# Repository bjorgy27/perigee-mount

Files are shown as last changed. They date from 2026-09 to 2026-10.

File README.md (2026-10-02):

# PERIGEE gimbal

Fully 3D-printed azimuth/elevation pedestal for a dish up to 1 m (mesh), 15-20 lb payload, driven directly by two
goBILDA Stingray servo gearboxes (Stingray-4 on azimuth, 450 deg of travel; Stingray-9 on elevation, 200 deg), both
run open loop: they are positional servos, the pulse width is the position, and there is no encoder or feedback wire.
Controlled by an ST Nucleo-F401RE on the rotating head (USB serial to the PC running Perigee). Azimuth needs no slip ring: 1.25 turns
of travel run on a cable service loop. The azimuth axis runs on a greased printed plain bearing; elevation runs on the
Stingray-9's own ball-bearing hub-shaft on the right and a printed split bushing on the left. The only non-printed parts
are metric screws and nuts, the two gearboxes and the electronics.

Everything here is generated from `params.json` by `build.py` running inside FreeCAD 1.1 (headless).

```
./build.sh                              # regenerate everything (about 30 s): parts, assembly, exploded view, audit, exports, viewer bundle
.venv/bin/python tools_render.py        # OpenGL inspection renders into out/renders (moderngl on headless EGL, ~1 s)
.venv/bin/python tools_render.py --anim # cinematic assembly film -> out/renders/assembly.mp4 (30 fps, ~2 min)
.venv/bin/python tools_render.py --spot 1.5,9.5,36   # contact sheet of film frames at those seconds
python3 -m venv .venv && .venv/bin/pip install moderngl numpy pillow   # one-time renderer setup
```

The build also runs a **geometry audit** (every part one valid closed solid, BOP-checked, watertight mesh:
`out/geometry_audit.txt`) and an **overlap audit** over every pair of parts and every fastener against every part
(`out/overlap_audit.txt`); both must say `clean`. Export folders are wiped and regenerated on every build, so no
stale parts from older revisions linger. It also creates an **Exploded_Assembly** view (Assembly workbench > Exploded Views) with one move per part in assembly order,
so FreeCAD itself can animate the explosion with its slider.

## Hardware is real, and nothing threads into plastic
Every screw and nut is modelled (about 170 pieces) as App::Link instances of master parts in
`Hardware_Library`, placed with the same coordinates that cut their counterbores, nut pockets and nut traps.
All fasteners are ISO 4762 socket head cap screws in M3 / M4 / M5 with ISO 4032 hex nuts. No heat-set inserts and
no self-tapping: each bolt ends in a nut, or in one of the gearboxes' own M4 threads, that sits either in a blind hex pocket on the far face (where that face is
reachable at assembly time) or in a side-loaded nut trap (a slot the nut slides into before the mating part goes on:
pedestal wall, pillar feet, arm feet, shoulder ribs, around the left bore, lens window, hub rim), or in one of the Stingray-9's own
threads (3x M4 along the axis into the tapped holes in the back face of its aluminium block; its 16 mm-grid holes are
plain 4 mm holes, not tapped). The hub is
a hollow box with a bolted lid so all its flange nuts sit inside. The BOM lists exact counts per size and length.
Tools: 2.5 / 3 / 4 mm hex keys and 5.5 / 7 / 8 mm spanners.

## Styling
Canadarm / R.O.B. proportions: black pedestal with a wide flange plate, white azimuth housing under a plain round
yoke plate, two slender 60 mm round columns rising to 120 mm shoulder drums on the elevation axis (a half-circle cap over a
stadium-shaped lower half; both are 4 mm hollow shells open toward the hub), a
rounded black hub between them, round black boom and counterweight tubes, opaque black counterweight canister with an
orange cap. Translucent parts show the mechanism: the lens on the right drum over the Stingray-9, the access cover on
the yoke plate, the status window on the left cap. Cables run inside the hollow columns.
Filaments: white (housing, plate, columns, drums, bushings), black (pedestal, flange plate, hub, lid, stub, boom,
counterweight arm and canister), grey (left axis cap, adapter), orange (counterweight cap), translucent (lens,
access cover, window, light pipe).

## What you get

| Path | Contents |
|---|---|
| `out/PerigeeGimbal.FCStd` | Master file: Spreadsheet `Params`, Assembly `Gimbal` with 3 rigid groups, 2 joints (AZ + EL revolutes) and a `Track_Pass_Simulation` |
| `out/parts_fcstd/*.FCStd` | One FreeCAD file per printed part, already in print orientation |
| `out/step/*.step` | STEP per printed part (world coordinates) |
| `out/stl/*.stl` | STL per printed part, oriented for the Bambu A1 bed (largest is 236 mm) |
| `out/print/` | Print bundle: a folder per filament colour with those STLs, plus one 3MF per colour holding all of its parts for a Bambu Studio plate |
| `out/BOM.md` | Printed parts with filament colour and mass estimate, hardware list, key numbers |
| `out/manifest.json` | Machine-readable part list (group, colour, print bbox, volume) |
| `viewer/` | Interactive three.js viewer (`index.html` + `meta.json` + `parts_bundle.json`); pass simulation, fastener toggle, and an **Assemble** mode that builds the gimbal from the base up with a scrub bar |
| `out/renders/assembly.mp4` | Rendered assembly animation: 18 shots, each sub-assembly framed close from its best angle, 360 spins after the yoke and at the end, every fastener arriving along its own axis. Shot list = `SHOTS` in `build.py`, shared with the viewer |
| `macros/PerigeeColors.FCMacro` | Run once in the FreeCAD GUI: attaches the Assembly view providers (exploded view, joints, simulation), applies filament colours, hides joint markers |
| `macros/PerigeeAnimate.FCMacro` | Run in the GUI: animates an overhead pass with flip-over EL (no solver needed) |

### Animation inside FreeCAD
Open the master file, run `PerigeeColors.FCMacro`, then either run `PerigeeAnimate.FCMacro`, or open
Assembly workbench > Simulation > `Track_Pass_Simulation`, press *Generate* then *Play*. The simulation drives the AZ
and EL joints with formulas (`18*time` and a harmonic 0-180 deg sweep).

## Design summary (v9: Stingray direct drives, round columns, hollow 120 mm shoulder drums)

- **Frame**: Z up, AZ axis = Z, EL axis = X at z = 599 mm (510 mm above the deck). Boresight at EL 0 is +Y.
- **Pedestal**: black 216 mm pedestal body on a 236 mm foot flange (6x M6 for a mount plate), 75 mm tall; a black
  236 mm flange plate on top is the AZ retainer (split in two halves since v10: 8x M4x20 hooks in the pedestal, 4x
  M4x20 at the two lap notches) and the visible rotation seam. Everything fits a 256 mm
  bed with room for a brim.
- **AZ bearing**: printed plain bearing. The puck's 15 mm lip (OD 191) is the journal in the 192 mm bore; the step at
  the puck underside (r 84-96) is the greased thrust face; the flange plate traps the lip with 0.8 mm play. The
  Stingray-4's own bearings centre the shaft; the plain bearing carries the weight and moments.
- **AZ drive**: goBILDA Stingray-4 (3215-0001-0004, feedback mode) stands on four pillars on the pedestal floor,
  bolted from below (4x M4x40 into its 16 mm grid). Its output gear faces up and its four M4 standoffs bolt to the
  underside of the puck (4x M4x25 from the deck). 450 deg of travel, 100 kg.cm, 15 rpm. Open loop: the
  commanded pulse is the position. Cables pass through a hole in the puck into the pedestal annulus as a service loop.
- **AZ housing**: the rotating electronics bay is a white drum of the same 216 mm diameter as the pedestal body; four
  internal pillars tied to the wall by ribs carry the yoke (M4 top and bottom, nuts trapped in the pillars). Its lid is
  an oval 244 x 220 mm yoke plate with a translucent round access cover; the columns bolt to the plate from below and
  their cables pass up through it.
- **Yoke**: two hollow 60 mm round columns (3 mm walls), each printed as a lower segment and an upper segment joined
  by a solid spigot with 2x M4x50 across; the upper segment carries the lower half of a 120 mm shoulder drum on the
  elevation axis. The drum profile is a half-circle above the axis and a stadium below it (straight sides for 20 mm,
  then a half-circle: the Stingray-9 hangs 70 mm below the axis and the columns' foot pattern is fixed by the printed
  yoke plate, so the lower half has to reach 80 mm down). Both halves are 4 mm shells closed on the outer face and open
  toward the hub, with the internal ribs, channel and pillow block tied to the outer plate; they print lying on their
  flat outer face with no support. The caps have a 4 mm split-plane plate and bolt down with 2x M4x50 each into nuts
  36 mm deep in ribs of the lower half (traps open on the drum side). Feet: 4x M4x25 up from under the yoke plate into
  side-loaded nuts in a solid foot boss (unchanged from v8, so the printed plate still fits).
- **EL drive**: goBILDA Stingray-9 (3215-0001-0009, feedback mode) slides into a 3 mm-walled channel inside the right
  shoulder shell from the inner face, servo below the axis, and is screwed along its axis with 3x M4x20 through a
  12 mm back plate into the three tapped holes in the back face of its block (on a 22.6 mm circle around the shaft: one
  11.3 mm above the axis, two either side of it on the split plane), all driven with a 3 mm hex key through the 76 mm
  window on the outer face and a 36 mm sight bore before the lens goes on (v11; v10 screwed into the 16 mm-grid holes,
  which turned out to be plain, untapped 4 mm holes). The hub-shaft end and its snap ring stick 3.6 mm out of the back
  of the block into a 15 mm pocket in the back plate. Its 88 mm output gear turns in the gap between drum and hub and its four M4 standoffs bolt
  straight to the hub's right wall (4x M4x12 from inside the hub). 200 deg of travel; the firmware uses EL -2 to 185 of it, 227 kg.cm.
  The gearbox, its screws and the servo are visible through the translucent 88 mm lens, centred on the axis.
- **EL bearing, left**: a 30 mm stub axle bolts to the hub's left face (4x M4x20) and turns in a split printed
  bushing (36/30.5 x 40) inside the left drum; a plain left axis cover with a translucent status window closes the
  bore.
- **Cradle**: rounded 90 mm hollow hub (12 mm vertical, 3 mm top fillets) with a flush lid (4x M3x12 into nuts in a
  12 mm rim). All flange bolts end in nuts inside the cavity. Boom and counterweight arm are 40 mm round tubes with
  round 70 mm root flanges (4x M4x20 on a 42 mm square) and round spigots into the hub.
- **Dish interface**: boom ends in a 64 mm flange with four pocketed M5 nuts; bolt on the slotted plate adapter or the
  1.5 in pipe stub with 4x M5x12.
- **Counterweight**: opaque black canister (~1.3 L) on the square arm with a row of holes for balance adjustment;
  orange press cap with nuts pocketed in its plug.
- **Vendor CAD**: `vendor/3215-0001-000{4,9}/` hold goBILDA's STEP assemblies (120 MB each); the model uses measured
  envelopes (`STINGRAY` in `gimbal/parts.py`) split into a static part and an output part per axis.

## FEA
`freecadcmd -c "import runpy; runpy.run_path('tools_fea.py')"` writes `out/fea/`: the printed structure rebuilt without
fastener features and fused into one bonded solid (`Perigee_FEA_structure.step` / `.brep`, plus one STEP per rigid
group), and `Perigee_FEA.FCStd` with a FEM analysis set up: PLA material (stiffness derated for 30 % gyroid), the
foot fixed, dish weight and wind on the boom flange, counterweight on the arm end, gravity, and a CalculiX static
solver. The file already contains a second-order tetrahedral mesh (gmsh, 2.5 to 9 mm, about 450 k nodes) and
`out/fea/ccx/` holds the written CalculiX input deck.

gmsh is not in the Arch repos; the project venv has it (`.venv/bin/gmsh`, installed with pip). To re-mesh from the
FreeCAD GUI point Preferences > FEM > Gmsh at that binary, or edit the sizes in `tools_fea.py` and rerun. The solver
is in the AUR: `yay -S calculix-ccx`. Then either open the FCStd, double-click CalculiX and Run, or run
`ccx -i Perigee_FEA` inside `out/fea/ccx/` and load the `.frd` result. Two sliding fits (column spigots, hub
spigots) and the gearbox blocks and shafts are bonded PLA bridge solids in this model, so deflection at the joints is
overestimated; the canister is left out and its load applied on the counterweight arm.

### Parametric sweep (dish size x mass x wind x elevation)
`freecadcmd -c "import runpy; runpy.run_path('tools_fea_poses.py')"` rebuilds the bonded structure with the cradle
rotated to EL 0 / 45 / 90 (`out/fea/sweep/pose_*.brep`). Then `.venv/bin/python tools_fea_sweep.py mesh | solve | post`:
gmsh meshes each pose (~140 k nodes, straight-sided C3D10), CalculiX solves 9 unit load steps per pose (Fx Fy Fz Mx My Mz
on a rigid coupling at the boom flange, Fz Mx at the counterweight arm end, gravity; ~2 h per pose, run the three in
parallel), and `post` superposes them over the scenario grid in `tools_fea_sweep.py` (0.6-1.2 m dishes, 3-15 kg,
0-40 m/s head-on and side wind) in seconds, writing `out/fea/sweep/SWEEP.md` and `sweep.csv` (peak / 99.9th percentile
von Mises, safety factor, dish deflection, pointing error, counterweight needed, unbalanced EL moment). The `.frd` files
are ~400 MB each and are needed only to re-run `post`.

## Print notes
- ASA or PETG, 0.2 mm layers, 4-5 walls, 30-40 % gyroid for structural parts (base, puck, arms, hub, trunnions).
- Columns print lying on their outer side (as exported); the stencil letters then print without support.
- Shoulder halves and caps print on their flat outer face (as exported): the shells are open toward the hub, which is
  the top of the print, so there is nothing to bridge or support. They are all walls, so print them at 100 % (the mass
  estimate in the BOM, which assumes 45 % effective density, undercounts them: expect about 1.07 g per cm3).
- Lid and counterweight cap print face down; their PERIGEE logos are engraved so that works.
- Ball grooves are 45 deg V's and print clean. Sand lightly, then PTFE grease.
- Nut pockets are 7 mm AF (M4) and 5.5 mm AF (M3) with 0.4 to 0.5 mm clearance; nut traps are the same width, opening on a side face.

## Assembly order (matches the animation)
1. Base: Stingray-4 onto the four floor pillars, 4x M4x40 up from under the base into its grid holes; feed its
   cable out through the floor slot.
2. Hooks: slide 8 M4 nuts into the pedestal wall traps at 45 / 75 / 105 / 135 deg and their mirror images (the four
   traps next to the X axis stay empty). Lay both retainer halves on the empty pedestal in their final place, drop an
   M4x20 into each of the 8 slots and snug it onto the groove floor, then back each off about a quarter turn and
   slide the halves back out along +-Y. The screw heads are now hooks at exactly the right height.
3. Head: on the bench, slide nuts into the drum's pillar-foot traps, set the drum on the puck, 4x M4x30 up from under
   the puck. Grease the thrust face and bore, lower the puck + drum onto the gearbox standoffs (the lip passes inside
   the hooks), 4x M4x25 down from the deck into the standoffs, reached through the open top of the drum.
4. Retainer: slide half A in from +Y through the gap under the drum (its slots pass the hooks, its thin tongues end
   past the X axis), then half B from -Y with its tongues over A's. Push an M4 nut up into each of the 4 hex pockets
   under A's tongues (they sit outside the pedestal, so a fingertip reaches them) and drive 4x M4x20 down through the
   notches. Do this before the yoke plate goes on: the plate overhangs the notches in X.
5. Housing: electronics in; yoke plate 4x M4x16
   into the upper pillar traps. Lower columns 4x M4x25 each from under the plate into the foot traps (before the
   plate goes on). Upper columns: spigot into the socket, 2x M4x50 across + nuts.
6. Right drum: slide the Stingray-9 into its channel from the inner face (cap off), shaft end into the pocket in the
   back plate; through the window, 2x M4x20 into the two back-face threads on the split plane (half holes; the cap's
   halves slide down over them later); the M4x20 above the axis goes in after the cap (step 7). Then the translucent lens, 4x M3x12 into the window-loaded nuts (two of them sit in the cap).
7. Cradle: with the hub lid off, bolt the left stub (4x M4x20), boom and counterweight arm flanges (4x M4x20 each)
   with nuts inside the hub. Lower bushing half into the left shoulder, grease, drop the
   cradle in so the right wall meets the Stingray-9 standoffs, 4x M4x12 from inside the hub into the standoffs, lid
   4x M3x12. Upper bushing half, caps (2x M4x50 each into the rib traps), then the last M4x20 into the Stingray-9.
8. Left shoulder: axis cover 4x M3x12, press the window in.
9. Drop the 4 M5 nuts into the pockets on the back of the boom flange, adapter 4x M5x12. Canister collar 2x M4x55 +
   nuts; drop the 2 M3 nuts into the pockets in the cap's plug, push the cap on, 2x M3x10 through skirt and wall.
   Balance with the canister empty, then fill.

## Caveats you should know
- Both Stingrays must be the **feedback-mode** variants (3215-0001-xxxx) and driven by a controller that can produce
  the wide PWM range (500-2500 us) they need for their full 450 / 200 deg travel. "Feedback mode" only means
  positional mode: there is no feedback wire. The firmware (perigee-control/firmware/perigee_mount_stm32) keeps azimuth
  inside 0..400 deg of the 1.25-turn cable loop and elevation inside -2..185.
- The right EL bearing is the Stingray-9's own hub-shaft bearings; keep the payload balanced with the counterweight so
  the gearbox sees torque, not a permanent overhung load.
- Printed plain bearings need grease and a break-in; the AZ journal clearance is 0.5 mm radial and the retainer play
  0.8 mm. If the axis is stiff, sand the puck lip lightly. Replace the EL bushing when it wears.
- The file is written headless. FreeCAD's GUI opens such a file with every object hidden, so the build injects a
  `GuiDocument.xml` (`tools_guidoc.py`: visibility, filament colours, transparency) into the master and per-part files.
  Still run `PerigeeColors.FCMacro` once after opening: it attaches the Assembly workbench view providers to the joints,
  the Exploded_Assembly view and its steps, and the simulation. Until then double-clicking Exploded_Assembly does nothing.
- The Stingray placeholders are measured envelopes, not the vendor geometry; open the STEP files in `vendor/` when
  you need a detail (they are heavy).
- The Spreadsheet in the master file documents the parameters; it is regenerated by the script, not live-linked.

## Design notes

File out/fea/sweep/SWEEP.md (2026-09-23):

# Perigee gimbal FEA sweep (2026-09-23)

Generated by tools_fea_sweep.py. Linear static superposition of 9 unit load cases per elevation pose (tools_fea_poses.py
geometry: bonded, defeatured printed structure; PLA E = 2100 MPa, yield 30 MPa; foot fixed; CalculiX 2.23, gmsh).

Meshes: EL 0: 142,260 nodes; EL 45: 137,327 nodes; EL 90: 137,130 nodes

Loads per scenario: dish (+ 0.5 kg feed at the focus) weight and wind at the paraboloid centroid, f/D = 0.4, vertex 8 mm past the
boom flange; wind F = 1/2 rho v^2 A Cd, Cd = 0.3 + cos^2(alpha) (1.3 head-on, solid dish); counterweight fill sized to balance
the dish at EL 0 (lead-shot cap 7.8 kg), canister + fill weight at the canister centre; gravity on the structure. SF = yield / peak
von Mises. Peak values sit at re-entrant corners of the bonded model and are conservative; the 99.9th percentile is also given.

## Verification against the fine-mesh run (out/fea/RESULTS.md, 372k nodes, same loads at EL 0)

| Quantity | Fine mesh 2026-09-21 | This mesh + rigid flange coupling |
|---|---|---|
| Peak von Mises | 2.68 MPa | 2.91 MPa (columns) |
| 99.9th percentile von Mises | 2.09 MPa | 2.52 MPa |
| Deflection at the boom flange | 2.9 mm | 3.76 mm |
| Deflection at the counterweight arm end | 3.6 mm | 3.47 mm |

## Worst case over elevation pose and wind direction

| Dish | Mass | Wind | Wind force | CW fill | Peak vM | p99.9 vM | SF | Where | Dish deflection | Pointing error |
|---|---|---|---|---|---|---|---|---|---|---|
| 0.6 m | 3 kg | 0 m/s | 0 N | 2.6 kg | 1.76 MPa | 1.50 | 17.0 | cradle (hub/boom/arm), EL 0, calm | 0.3 mm | 0.20 deg |
| 0.6 m | 3 kg | 10 m/s | 23 N | 2.6 kg | 1.81 MPa | 1.51 | 16.6 | cradle (hub/boom/arm), EL 0, head-on (+Y) | 0.7 mm | 0.31 deg |
| 0.6 m | 3 kg | 15 m/s | 31 N | 2.6 kg | 2.28 MPa | 1.73 | 13.1 | cradle (hub/boom/arm), EL 45, head-on (+Y) | 1.9 mm | 0.51 deg |
| 0.6 m | 3 kg | 20 m/s | 55 N | 2.6 kg | 3.05 MPa | 2.28 | 9.8 | cradle (hub/boom/arm), EL 45, head-on (+Y) | 3.2 mm | 0.79 deg |
| 0.6 m | 3 kg | 25 m/s | 87 N | 2.6 kg | 4.03 MPa | 2.99 | 7.4 | cradle (hub/boom/arm), EL 45, head-on (+Y) | 4.9 mm | 1.14 deg |
| 0.6 m | 3 kg | 30 m/s | 125 N | 2.6 kg | 5.24 MPa | 3.96 | 5.7 | cradle (hub/boom/arm), EL 45, head-on (+Y) | 6.9 mm | 1.57 deg |
| 0.6 m | 3 kg | 40 m/s | 222 N | 2.6 kg | 8.30 MPa | 6.45 | 3.6 | cradle (hub/boom/arm), EL 45, head-on (+Y) | 12.2 mm | 2.66 deg |
| 0.6 m | 6 kg | 0 m/s | 0 N | 4.6 kg | 3.09 MPa | 2.62 | 9.7 | cradle (hub/boom/arm), EL 0, calm | 0.5 mm | 0.35 deg |
| 0.6 m | 6 kg | 10 m/s | 23 N | 4.6 kg | 3.10 MPa | 2.62 | 9.7 | cradle (hub/boom/arm), EL 0, head-on (+Y) | 0.9 mm | 0.45 deg |
| 0.6 m | 6 kg | 15 m/s | 31 N | 4.6 kg | 3.26 MPa | 2.48 | 9.2 | cradle (hub/boom/arm), EL 45, head-on (+Y) | 2.0 mm | 0.63 deg |
| 0.6 m | 6 kg | 20 m/s | 55 N | 4.6 kg | 3.99 MPa | 3.02 | 7.5 | cradle (hub/boom/arm), EL 45, head-on (+Y) | 3.3 mm | 0.91 deg |
| 0.6 m | 6 kg | 25 m/s | 87 N | 4.6 kg | 4.97 MPa | 3.72 | 6.0 | cradle (hub/boom/arm), EL 45, head-on (+Y) | 5.0 mm | 1.26 deg |
| 0.6 m | 6 kg | 30 m/s | 125 N | 4.6 kg | 6.18 MPa | 4.59 | 4.9 | cradle (hub/boom/arm), EL 45, head-on (+Y) | 7.1 mm | 1.69 deg |
| 0.6 m | 6 kg | 40 m/s | 222 N | 4.6 kg | 9.24 MPa | 6.99 | 3.2 | cradle (hub/boom/arm), EL 45, head-on (+Y) | 12.3 mm | 2.78 deg |
| 0.6 m | 9 kg | 0 m/s | 0 N | 6.6 kg | 4.42 MPa | 3.73 | 6.8 | cradle (hub/boom/arm), EL 0, calm | 0.7 mm | 0.50 deg |
| 0.6 m | 9 kg | 10 m/s | 23 N | 6.6 kg | 4.42 MPa | 3.74 | 6.8 | cradle (hub/boom/arm), EL 0, head-on (+Y) | 1.1 mm | 0.60 deg |
| 0.6 m | 9 kg | 15 m/s | 51 N | 6.6 kg | 4.43 MPa | 3.75 | 6.8 | cradle (hub/boom/arm), EL 0, head-on (+Y) | 1.8 mm | 0.73 deg |
| 0.6 m | 9 kg | 20 m/s | 55 N | 6.6 kg | 4.94 MPa | 3.76 | 6.1 | cradle (hub/boom/arm), EL 45, head-on (+Y) | 3.5 mm | 1.03 deg |
| 0.6 m | 9 kg | 25 m/s | 87 N | 6.6 kg | 5.92 MPa | 4.45 | 5.1 | cradle (hub/boom/arm), EL 45, head-on (+Y) | 5.2 mm | 1.38 deg |
| 0.6 m | 9 kg | 30 m/s | 125 N | 6.6 kg | 7.12 MPa | 5.31 | 4.2 | cradle (hub/boom/arm), EL 45, head-on (+Y) | 7.2 mm | 1.81 deg |
| 0.6 m | 9 kg | 40 m/s | 222 N | 6.6 kg | 10.18 MPa | 7.55 | 2.9 | cradle (hub/boom/arm), EL 45, head-on (+Y) | 12.5 mm | 2.90 deg |
| 0.6 m | 12 kg | 0 m/s | 0 N | 7.8 kg (needs 8.7) | 5.57 MPa | 4.53 | 5.4 | cradle (hub/boom/arm), EL 0, calm | 1.1 mm | 0.70 deg |
| 0.6 m | 12 kg | 10 m/s | 23 N | 7.8 kg (needs 8.7) | 5.62 MPa | 4.53 | 5.3 | cradle (hub/boom/arm), EL 0, head-on (+Y) | 1.5 mm | 0.80 deg |
| 0.6 m | 12 kg | 15 m/s | 51 N | 7.8 kg (needs 8.7) | 5.69 MPa | 4.55 | 5.3 | cradle (hub/boom/arm), EL 0, head-on (+Y) | 2.2 mm | 0.93 deg |
| 0.6 m | 12 kg | 20 m/s | 55 N | 7.8 kg (needs 8.7) | 5.91 MPa | 4.45 | 5.1 | cradle (hub/boom/arm), EL 45, head-on (+Y) | 3.8 mm | 1.18 deg |
| 0.6 m | 12 kg | 25 m/s | 87 N | 7.8 kg (needs 8.7) | 6.81 MPa | 5.17 | 4.4 | cradle (hub/boom/arm), EL 45, head-on (+Y) | 5.5 mm | 1.53 deg |
| 0.6 m | 12 kg | 30 m/s | 125 N | 7.8 kg (needs 8.7) | 8.01 MPa | 6.00 | 3.7 | cradle (hub/boom/arm), EL 45, head-on (+Y) | 7.6 mm | 1.96 deg |
| 0.6 m | 12 kg | 40 m/s | 222 N | 7.8 kg (needs 8.7) | 11.08 MPa | 8.24 | 2.7 | cradle (hub/boom/arm), EL 45, head-on (+Y) | 12.8 mm | 3.06 deg |
| 0.6 m | 15 kg | 0 m/s | 0 N | 7.8 kg (needs 10.7) | 6.83 MPa | 5.11 | 4.4 | cradle (hub/boom/arm), EL 0, calm | 1.7 mm | 0.97 deg |
| 0.6 m | 15 kg | 10 m/s | 23 N | 7.8 kg (needs 10.7) | 6.88 MPa | 5.11 | 4.4 | cradle (hub/boom/arm), EL 0, head-on (+Y) | 2.1 mm | 1.08 deg |
| 0.6 m | 15 kg | 15 m/s | 51 N | 7.8 kg (needs 10.7) | 6.95 MPa | 5.13 | 4.3 | cradle (hub/boom/arm), EL 0, head-on (+Y) | 2.8 mm | 1.21 deg |
| 0.6 m | 15 kg | 20 m/s | 90 N | 7.8 kg (needs 10.7) | 7.04 MPa | 5.13 | 4.3 | cradle (hub/boom/arm), EL 0, head-on (+Y) | 3.8 mm | 1.39 deg |
| 0.6 m | 15 kg | 25 m/s | 87 N | 7.8 kg (needs 10.7) | 7.68 MPa | 5.83 | 3.9 | cradle (hub/boom/arm), EL 45, head-on (+Y) | 6.1 mm | 1.73 deg |
| 0.6 m | 15 kg | 30 m/s | 125 N | 7.8 kg (needs 10.7) | 8.85 MPa | 6.70 | 3.4 | cradle (hub/boom/arm), EL 45, head-on (+Y) | 8.2 mm | 2.16 deg |
| 0.6 m | 15 kg | 40 m/s | 222 N | 7.8 kg (needs 10.7) | 11.91 MPa | 8.94 | 2.5 | cradle (hub/boom/arm), EL 45, head-on (+Y) | 13.4 mm | 3.25 deg |
| 0.8 m | 3 kg | 0 m/s | 0 N | 2.9 kg | 1.99 MPa | 1.68 | 15.0 | cradle (hub/boom/arm), EL 0, calm | 0.3 mm | 0.23 deg |
| 0.8 m | 3 kg | 10 m/s | 25 N | 2.9 kg | 2.33 MPa | 1.81 | 12.9 | cradle (hub/boom/arm), EL 45, head-on (+Y) | 1.5 mm | 0.48 deg |
| 0.8 m | 3 kg | 15 m/s | 55 N | 2.9 kg | 3.40 MPa | 2.59 | 8.8 | cradle (hub/boom/arm), EL 45, head-on (+Y) | 3.2 mm | 0.84 deg |
| 0.8 m | 3 kg | 20 m/s | 99 N | 2.9 kg | 4.89 MPa | 3.69 | 6.1 | cradle (hub/boom/arm), EL 45, head-on (+Y) | 5.6 mm | 1.35 deg |
| 0.8 m | 3 kg | 25 m/s | 154 N | 2.9 kg | 6.81 MPa | 5.23 | 4.4 | cradle (hub/boom/arm), EL 45, head-on (+Y) | 8.6 mm | 2.01 deg |
| 0.8 m | 3 kg | 30 m/s | 222 N | 2.9 kg | 9.16 MPa | 7.14 | 3.3 | cradle (hub/boom/arm), EL 45, head-on (+Y) | 12.3 mm | 2.82 deg |
| 0.8 m | 3 kg | 40 m/s | 394 N | 2.9 kg | 15.13 MPa | 11.97 | 2.0 | cradle (hub/boom/arm), EL 45, head-on (+Y) | 21.8 mm | 4.86 deg |
| 0.8 m | 6 kg | 0 m/s | 0 N | 5.1 kg | 3.40 MPa | 2.90 | 8.8 | cradle (hub/boom/arm), EL 0, calm | 0.5 mm | 0.39 deg |
| 0.8 m | 6 kg | 10 m/s | 40 N | 5.1 kg | 3.49 MPa | 2.91 | 8.6 | cradle (hub/boom/arm), EL 0, head-on (+Y) | 1.3 mm | 0.58 deg |
| 0.8 m | 6 kg | 15 m/s | 55 N | 5.1 kg | 4.44 MPa | 3.41 | 6.8 | cradle (hub/boom/arm), EL 45, head-on (+Y) | 3.3 mm | 0.97 deg |
| 0.8 m | 6 kg | 20 m/s | 99 N | 5.1 kg | 5.93 MPa | 4.51 | 5.1 | cradle (hub/boom/arm), EL 45, head-on (+Y) | 5.7 mm | 1.49 deg |
| 0.8 m | 6 kg | 25 m/s | 154 N | 5.1 kg | 7.85 MPa | 5.91 | 3.8 | cradle (hub/boom/arm), EL 45, head-on (+Y) | 8.8 mm | 2.14 deg |
| 0.8 m | 6 kg | 30 m/s | 222 N | 5.1 kg | 10.20 MPa | 7.76 | 2.9 | cradle (hub/boom/arm), EL 45, head-on (+Y) | 12.5 mm | 2.95 deg |
| 0.8 m | 6 kg | 40 m/s | 394 N | 5.1 kg | 16.17 MPa | 12.65 | 1.9 | cradle (hub/boom/arm), EL 45, head-on (+Y) | 21.9 mm | 5.00 deg |
| 0.8 m | 9 kg | 0 m/s | 0 N | 7.2 kg | 4.81 MPa | 4.11 | 6.2 | cradle (hub/boom/arm), EL 0, calm | 0.7 mm | 0.55 deg |
| 0.8 m | 9 kg | 10 m/s | 40 N | 7.2 kg | 4.90 MPa | 4.13 | 6.1 | cradle (hub/boom/arm), EL 0, head-on (+Y) | 1.5 mm | 0.74 deg |
| 0.8 m | 9 kg | 15 m/s | 55 N | 7.2 kg | 5.48 MPa | 4.23 | 5.5 | cradle (hub/boom/arm), EL 45, head-on (+Y) | 3.5 mm | 1.11 deg |
| 0.8 m | 9 kg | 20 m/s | 99 N | 7.2 kg | 6.97 MPa | 5.34 | 4.3 | cradle (hub/boom/arm), EL 45, head-on (+Y) | 5.9 mm | 1.62 deg |
| 0.8 m | 9 kg | 25 m/s | 154 N | 7.2 kg | 8.89 MPa | 6.73 | 3.4 | cradle (hub/boom/arm), EL 45, head-on (+Y) | 8.9 mm | 2.28 deg |
| 0.8 m | 9 kg | 30 m/s | 222 N | 7.2 kg | 11.24 MPa | 8.46 | 2.7 | cradle (hub/boom/arm), EL 45, head-on (+Y) | 12.6 mm | 3.08 deg |
| 0.8 m | 9 kg | 40 m/s | 394 N | 7.2 kg | 17.21 MPa | 13.23 | 1.7 | cradle (hub/boom/arm), EL 45, head-on (+Y) | 22.1 mm | 5.13 deg |
| 0.8 m | 12 kg | 0 m/s | 0 N | 7.8 kg (needs 9.4) | 6.20 MPa | 4.81 | 4.8 | cradle (hub/boom/arm), EL 0, calm | 1.2 mm | 0.82 deg |
| 0.8 m | 12 kg | 10 m/s | 40 N | 7.8 kg (needs 9.4) | 6.29 MPa | 4.81 | 4.8 | cradle (hub/boom/arm), EL 0, head-on (+Y) | 2.0 mm | 1.00 deg |
| 0.8 m | 12 kg | 15 m/s | 55 N | 7.8 kg (needs 9.4) | 6.50 MPa | 5.01 | 4.6 | cradle (hub/boom/arm), EL 45, head-on (+Y) | 4.0 mm | 1.30 deg |
| 0.8 m | 12 kg | 20 m/s | 99 N | 7.8 kg (needs 9.4) | 7.93 MPa | 6.08 | 3.8 | cradle (hub/boom/arm), EL 45, head-on (+Y) | 6.4 mm | 1.81 deg |
| 0.8 m | 12 kg | 25 m/s | 154 N | 7.8 kg (needs 9.4) | 9.85 MPa | 7.51 | 3.0 | cradle (hub/boom/arm), EL 45, head-on (+Y) | 9.4 mm | 2.47 deg |
| 0.8 m | 12 kg | 30 m/s | 222 N | 7.8 kg (needs 9.4) | 12.19 MPa | 9.22 | 2.5 | cradle (hub/boom/arm), EL 45, head-on (+Y) | 13.1 mm | 3.27 deg |
| 0.8 m | 12 kg | 40 m/s | 394 N | 7.8 kg (needs 9.4) | 18.17 MPa | 14.01 | 1.7 | cradle (hub/boom/arm), EL 45, head-on (+Y) | 22.6 mm | 5.32 deg |
| 0.8 m | 15 kg | 0 m/s | 0 N | 7.8 kg (needs 11.6) | 7.59 MPa | 5.77 | 4.0 | cradle (hub/boom/arm), EL 0, calm | 1.9 mm | 1.12 deg |
| 0.8 m | 15 kg | 10 m/s | 40 N | 7.8 kg (needs 11.6) | 7.68 MPa | 5.78 | 3.9 | cradle (hub/boom/arm), EL 0, head-on (+Y) | 2.7 mm | 1.31 deg |
| 0.8 m | 15 kg | 15 m/s | 90 N | 7.8 kg (needs 11.6) | 7.80 MPa | 5.79 | 3.8 | cradle (hub/boom/arm), EL 0, head-on (+Y) | 4.0 mm | 1.54 deg |
| 0.8 m | 15 kg | 20 m/s | 99 N | 7.8 kg (needs 11.6) | 8.85 MPa | 6.82 | 3.4 | cradle (hub/boom/arm), EL 45, head-on (+Y) | 7.0 mm | 2.02 deg |
| 0.8 m | 15 kg | 25 m/s | 154 N | 7.8 kg (needs 11.6) | 10.77 MPa | 8.26 | 2.8 | cradle (hub/boom/arm), EL 45, head-on (+Y) | 10.0 mm | 2.68 deg |
| 0.8 m | 15 kg | 30 m/s | 222 N | 7.8 kg (needs 11.6) | 13.12 MPa | 9.99 | 2.3 | cradle (hub/boom/arm), EL 45, head-on (+Y) | 13.7 mm | 3.49 deg |
| 0.8 m | 15 kg | 40 m/s | 394 N | 7.8 kg (needs 11.6) | 19.09 MPa | 14.79 | 1.6 | cradle (hub/boom/arm), EL 45, head-on (+Y) | 23.2 mm | 5.53 deg |
| 1.0 m | 3 kg | 0 m/s | 0 N | 3.2 kg | 2.23 MPa | 1.88 | 13.4 | cradle (hub/boom/arm), EL 0, calm | 0.3 mm | 0.26 deg |
| 1.0 m | 3 kg | 10 m/s | 38 N | 3.2 kg | 3.11 MPa | 2.44 | 9.6 | cradle (hub/boom/arm), EL 45, head-on (+Y) | 2.3 mm | 0.69 deg |
| 1.0 m | 3 kg | 15 m/s | 87 N | 3.2 kg | 4.93 MPa | 3.78 | 6.1 | cradle (hub/boom/arm), EL 45, head-on (+Y) | 4.9 mm | 1.29 deg |
| 1.0 m | 3 kg | 20 m/s | 154 N | 3.2 kg | 7.47 MPa | 5.73 | 4.0 | cradle (hub/boom/arm), EL 45, head-on (+Y) | 8.7 mm | 2.13 deg |
| 1.0 m | 3 kg | 25 m/s | 241 N | 3.2 kg | 10.73 MPa | 8.40 | 2.8 | cradle (hub/boom/arm), EL 45, head-on (+Y) | 13.5 mm | 3.21 deg |
| 1.0 m | 3 kg | 30 m/s | 346 N | 3.2 kg | 14.72 MPa | 11.69 | 2.0 | cradle (hub/boom/arm), EL 45, head-on (+Y) | 19.4 mm | 4.53 deg |
| 1.0 m | 3 kg | 40 m/s | 616 N | 3.2 kg | 24.88 MPa | 19.93 | 1.2 | cradle (hub/boom/arm), EL 45, head-on (+Y) | 34.4 mm | 7.89 deg |
| 1.0 m | 6 kg | 0 m/s | 0 N | 5.5 kg | 3.77 MPa | 3.19 | 8.0 | cradle (hub/boom/arm), EL 0, calm | 0.6 mm | 0.43 deg |
| 1.0 m | 6 kg | 10 m/s | 38 N | 5.5 kg | 4.25 MPa | 3.33 | 7.1 | cradle (hub/boom/arm), EL 45, head-on (+Y) | 2.4 mm | 0.83 deg |
| 1.0 m | 6 kg | 15 m/s | 87 N | 5.5 kg | 6.07 MPa | 4.70 | 4.9 | cradle (hub/boom/arm), EL 45, head-on (+Y) | 5.1 mm | 1.43 deg |
| 1.0 m | 6 kg | 20 m/s | 154 N | 5.5 kg | 8.61 MPa | 6.57 | 3.5 | cradle (hub/boom/arm), EL 45, head-on (+Y) | 8.8 mm | 2.27 deg |
| 1.0 m | 6 kg | 25 m/s | 241 N | 5.5 kg | 11.87 MPa | 9.07 | 2.5 | cradle (hub/boom/arm), EL 45, head-on (+Y) | 13.7 mm | 3.35 deg |
| 1.0 m | 6 kg | 30 m/s | 346 N | 5.5 kg | 15.86 MPa | 12.36 | 1.9 | cradle (hub/boom/arm), EL 45, head-on (+Y) | 19.5 mm | 4.67 deg |
| 1.0 m | 6 kg | 40 m/s | 616 N | 5.5 kg | 26.02 MPa | 20.68 | 1.2 | cradle (hub/boom/arm), EL 45, head-on (+Y) | 34.6 mm | 8.03 deg |
| 1.0 m | 9 kg | 0 m/s | 0 N | 7.8 kg (needs 7.8) | 5.30 MPa | 4.48 | 5.7 | cradle (hub/boom/arm), EL 0, calm | 0.8 mm | 0.61 deg |
| 1.0 m | 9 kg | 10 m/s | 63 N | 7.8 kg (needs 7.8) | 5.45 MPa | 4.52 | 5.5 | cradle (hub/boom/arm), EL 0, head-on (+Y) | 2.0 mm | 0.90 deg |
| 1.0 m | 9 kg | 15 m/s | 87 N | 7.8 kg (needs 7.8) | 7.20 MPa | 5.60 | 4.2 | cradle (hub/boom/arm), EL 45, head-on (+Y) | 5.2 mm | 1.58 deg |
| 1.0 m | 9 kg | 20 m/s | 154 N | 7.8 kg (needs 7.8) | 9.74 MPa | 7.49 | 3.1 | cradle (hub/boom/arm), EL 45, head-on (+Y) | 9.0 mm | 2.42 deg |
| 1.0 m | 9 kg | 25 m/s | 241 N | 7.8 kg (needs 7.8) | 13.01 MPa | 9.91 | 2.3 | cradle (hub/boom/arm), EL 45, head-on (+Y) | 13.8 mm | 3.50 deg |
| 1.0 m | 9 kg | 30 m/s | 346 N | 7.8 kg (needs 7.8) | 17.00 MPa | 13.00 | 1.8 | cradle (hub/boom/arm), EL 45, head-on (+Y) | 19.7 mm | 4.82 deg |
| 1.0 m | 9 kg | 40 m/s | 616 N | 7.8 kg (needs 7.8) | 27.16 MPa | 21.40 | 1.1 | cradle (hub/boom/arm), EL 45, head-on (+Y) | 34.7 mm | 8.18 deg |
| 1.0 m | 12 kg | 0 m/s | 0 N | 7.8 kg (needs 10.2) | 6.82 MPa | 5.27 | 4.4 | cradle (hub/boom/arm), EL 0, calm | 1.4 mm | 0.94 deg |
| 1.0 m | 12 kg | 10 m/s | 63 N | 7.8 kg (needs 10.2) | 6.97 MPa | 5.28 | 4.3 | cradle (hub/boom/arm), EL 0, head-on (+Y) | 2.7 mm | 1.23 deg |
| 1.0 m | 12 kg | 15 m/s | 87 N | 7.8 kg (needs 10.2) | 8.22 MPa | 6.42 | 3.6 | cradle (hub/boom/arm), EL 45, head-on (+Y) | 5.9 mm | 1.81 deg |
| 1.0 m | 12 kg | 20 m/s | 154 N | 7.8 kg (needs 10.2) | 10.76 MPa | 8.33 | 2.8 | cradle (hub/boom/arm), EL 45, head-on (+Y) | 9.6 mm | 2.65 deg |
| 1.0 m | 12 kg | 25 m/s | 241 N | 7.8 kg (needs 10.2) | 14.03 MPa | 10.74 | 2.1 | cradle (hub/boom/arm), EL 45, head-on (+Y) | 14.4 mm | 3.73 deg |
| 1.0 m | 12 kg | 30 m/s | 346 N | 7.8 kg (needs 10.2) | 18.02 MPa | 13.91 | 1.7 | cradle (hub/boom/arm), EL 45, head-on (+Y) | 20.3 mm | 5.05 deg |
| 1.0 m | 12 kg | 40 m/s | 616 N | 7.8 kg (needs 10.2) | 28.18 MPa | 22.20 | 1.1 | cradle (hub/boom/arm), EL 45, head-on (+Y) | 35.3 mm | 8.41 deg |
| 1.0 m | 15 kg | 0 m/s | 0 N | 7.8 kg (needs 12.5) | 8.34 MPa | 6.44 | 3.6 | cradle (hub/boom/arm), EL 0, calm | 2.1 mm | 1.27 deg |
| 1.0 m | 15 kg | 10 m/s | 63 N | 7.8 kg (needs 12.5) | 8.49 MPa | 6.45 | 3.5 | cradle (hub/boom/arm), EL 0, head-on (+Y) | 3.4 mm | 1.56 deg |
| 1.0 m | 15 kg | 15 m/s | 87 N | 7.8 kg (needs 12.5) | 9.24 MPa | 7.24 | 3.2 | cradle (hub/boom/arm), EL 45, head-on (+Y) | 6.5 mm | 2.04 deg |
| 1.0 m | 15 kg | 20 m/s | 154 N | 7.8 kg (needs 12.5) | 11.78 MPa | 9.18 | 2.5 | cradle (hub/boom/arm), EL 45, head-on (+Y) | 10.2 mm | 2.88 deg |
| 1.0 m | 15 kg | 25 m/s | 241 N | 7.8 kg (needs 12.5) | 15.04 MPa | 11.60 | 2.0 | cradle (hub/boom/arm), EL 45, head-on (+Y) | 15.1 mm | 3.96 deg |
| 1.0 m | 15 kg | 30 m/s | 346 N | 7.8 kg (needs 12.5) | 19.03 MPa | 14.84 | 1.6 | cradle (hub/boom/arm), EL 45, head-on (+Y) | 21.0 mm | 5.28 deg |
| 1.0 m | 15 kg | 40 m/s | 616 N | 7.8 kg (needs 12.5) | 29.19 MPa | 23.07 | 1.0 | cradle (hub/boom/arm), EL 45, head-on (+Y) | 36.0 mm | 8.64 deg |
| 1.2 m | 3 kg | 0 m/s | 0 N | 3.4 kg | 2.47 MPa | 2.08 | 12.1 | cradle (hub/boom/arm), EL 0, calm | 0.4 mm | 0.28 deg |
| 1.2 m | 3 kg | 10 m/s | 55 N | 3.4 kg | 4.10 MPa | 3.22 | 7.3 | cradle (hub/boom/arm), EL 45, head-on (+Y) | 3.2 mm | 0.95 deg |
| 1.2 m | 3 kg | 15 m/s | 125 N | 3.4 kg | 6.93 MPa | 5.36 | 4.3 | cradle (hub/boom/arm), EL 45, head-on (+Y) | 7.1 mm | 1.86 deg |
| 1.2 m | 3 kg | 20 m/s | 222 N | 3.4 kg | 10.88 MPa | 8.52 | 2.8 | cradle (hub/boom/arm), EL 45, head-on (+Y) | 12.6 mm | 3.13 deg |
| 1.2 m | 3 kg | 25 m/s | 346 N | 3.4 kg | 15.97 MPa | 12.69 | 1.9 | cradle (hub/boom/arm), EL 45, head-on (+Y) | 19.7 mm | 4.76 deg |
| 1.2 m | 3 kg | 30 m/s | 499 N | 3.4 kg | 22.19 MPa | 17.81 | 1.4 | cradle (hub/boom/arm), EL 45, head-on (+Y) | 28.3 mm | 6.75 deg |
| 1.2 m | 3 kg | 40 m/s | 887 N | 3.4 kg | 38.01 MPa | 30.78 | 0.8 | cradle (hub/boom/arm), EL 45, head-on (+Y) | 50.1 mm | 11.82 deg |
| 1.2 m | 6 kg | 0 m/s | 0 N | 5.9 kg | 4.14 MPa | 3.48 | 7.2 | cradle (hub/boom/arm), EL 0, calm | 0.6 mm | 0.48 deg |
| 1.2 m | 6 kg | 10 m/s | 55 N | 5.9 kg | 5.34 MPa | 4.22 | 5.6 | cradle (hub/boom/arm), EL 45, head-on (+Y) | 3.4 mm | 1.11 deg |
| 1.2 m | 6 kg | 15 m/s | 125 N | 5.9 kg | 8.17 MPa | 6.34 | 3.7 | cradle (hub/boom/arm), EL 45, head-on (+Y) | 7.3 mm | 2.01 deg |
| 1.2 m | 6 kg | 20 m/s | 222 N | 5.9 kg | 12.12 MPa | 9.35 | 2.5 | cradle (hub/boom/arm), EL 45, head-on (+Y) | 12.7 mm | 3.28 deg |
| 1.2 m | 6 kg | 25 m/s | 346 N | 5.9 kg | 17.21 MPa | 13.42 | 1.7 | cradle (hub/boom/arm), EL 45, head-on (+Y) | 19.8 mm | 4.91 deg |
| 1.2 m | 6 kg | 30 m/s | 499 N | 5.9 kg | 23.43 MPa | 18.50 | 1.3 | cradle (hub/boom/arm), EL 45, head-on (+Y) | 28.4 mm | 6.91 deg |
| 1.2 m | 6 kg | 40 m/s | 887 N | 5.9 kg | 39.25 MPa | 31.55 | 0.8 | cradle (hub/boom/arm), EL 45, head-on (+Y) | 50.3 mm | 11.98 deg |
| 1.2 m | 9 kg | 0 m/s | 0 N | 7.8 kg (needs 8.5) | 5.80 MPa | 4.72 | 5.2 | cradle (hub/boom/arm), EL 0, calm | 0.9 mm | 0.71 deg |
| 1.2 m | 9 kg | 10 m/s | 55 N | 7.8 kg (needs 8.5) | 6.55 MPa | 5.17 | 4.6 | cradle (hub/boom/arm), EL 45, head-on (+Y) | 3.6 mm | 1.29 deg |
| 1.2 m | 9 kg | 15 m/s | 125 N | 7.8 kg (needs 8.5) | 9.37 MPa | 7.33 | 3.2 | cradle (hub/boom/arm), EL 45, head-on (+Y) | 7.5 mm | 2.19 deg |
| 1.2 m | 9 kg | 20 m/s | 222 N | 7.8 kg (needs 8.5) | 13.33 MPa | 10.29 | 2.3 | cradle (hub/boom/arm), EL 45, head-on (+Y) | 13.0 mm | 3.46 deg |
| 1.2 m | 9 kg | 25 m/s | 346 N | 7.8 kg (needs 8.5) | 18.41 MPa | 14.20 | 1.6 | cradle (hub/boom/arm), EL 45, head-on (+Y) | 20.0 mm | 5.09 deg |
| 1.2 m | 9 kg | 30 m/s | 499 N | 7.8 kg (needs 8.5) | 24.63 MPa | 19.34 | 1.2 | cradle (hub/boom/arm), EL 45, head-on (+Y) | 28.6 mm | 7.09 deg |
| 1.2 m | 9 kg | 40 m/s | 887 N | 7.8 kg (needs 8.5) | 40.45 MPa | 32.37 | 0.7 | cradle (hub/boom/arm), EL 45, head-on (+Y) | 50.5 mm | 12.16 deg |
| 1.2 m | 12 kg | 0 m/s | 0 N | 7.8 kg (needs 11.0) | 7.45 MPa | 5.84 | 4.0 | cradle (hub/boom/arm), EL 0, calm | 1.6 mm | 1.06 deg |
| 1.2 m | 12 kg | 10 m/s | 55 N | 7.8 kg (needs 11.0) | 7.68 MPa | 6.08 | 3.9 | cradle (hub/boom/arm), EL 45, head-on (+Y) | 4.3 mm | 1.54 deg |
| 1.2 m | 12 kg | 15 m/s | 125 N | 7.8 kg (needs 11.0) | 10.48 MPa | 8.26 | 2.9 | cradle (hub/boom/arm), EL 45, head-on (+Y) | 8.2 mm | 2.44 deg |
| 1.2 m | 12 kg | 20 m/s | 222 N | 7.8 kg (needs 11.0) | 14.43 MPa | 11.21 | 2.1 | cradle (hub/boom/arm), EL 45, head-on (+Y) | 13.7 mm | 3.71 deg |
| 1.2 m | 12 kg | 25 m/s | 346 N | 7.8 kg (needs 11.0) | 19.52 MPa | 15.16 | 1.5 | cradle (hub/boom/arm), EL 45, head-on (+Y) | 20.7 mm | 5.34 deg |
| 1.2 m | 12 kg | 30 m/s | 499 N | 7.8 kg (needs 11.0) | 25.74 MPa | 20.31 | 1.2 | cradle (hub/boom/arm), EL 45, head-on (+Y) | 29.3 mm | 7.33 deg |
| 1.2 m | 12 kg | 40 m/s | 887 N | 7.8 kg (needs 11.0) | 41.56 MPa | 33.31 | 0.7 | cradle (hub/boom/arm), EL 45, head-on (+Y) | 51.2 mm | 12.41 deg |
| 1.2 m | 15 kg | 0 m/s | 0 N | 7.8 kg (needs 13.5) | 9.10 MPa | 7.12 | 3.3 | cradle (hub/boom/arm), EL 0, calm | 2.3 mm | 1.41 deg |
| 1.2 m | 15 kg | 10 m/s | 90 N | 7.8 kg (needs 13.5) | 9.31 MPa | 7.13 | 3.2 | cradle (hub/boom/arm), EL 0, head-on (+Y) | 4.3 mm | 1.83 deg |
| 1.2 m | 15 kg | 15 m/s | 125 N | 7.8 kg (needs 13.5) | 11.58 MPa | 9.17 | 2.6 | cradle (hub/boom/arm), EL 45, head-on (+Y) | 8.9 mm | 2.69 deg |
| 1.2 m | 15 kg | 20 m/s | 222 N | 7.8 kg (needs 13.5) | 15.54 MPa | 12.15 | 1.9 | cradle (hub/boom/arm), EL 45, head-on (+Y) | 14.3 mm | 3.96 deg |
| 1.2 m | 15 kg | 25 m/s | 346 N | 7.8 kg (needs 13.5) | 20.63 MPa | 16.14 | 1.5 | cradle (hub/boom/arm), EL 45, head-on (+Y) | 21.3 mm | 5.59 deg |
| 1.2 m | 15 kg | 30 m/s | 499 N | 7.8 kg (needs 13.5) | 26.84 MPa | 21.25 | 1.1 | cradle (hub/boom/arm), EL 45, head-on (+Y) | 29.9 mm | 7.58 deg |
| 1.2 m | 15 kg | 40 m/s | 887 N | 7.8 kg (needs 13.5) | 42.67 MPa | 34.21 | 0.7 | cradle (hub/boom/arm), EL 45, head-on (+Y) | 51.8 mm | 12.66 deg |

## Wind speed at which the safety factor drops below 2 (peak von Mises = 15 MPa), interpolated

| Dish | 3 kg | 6 kg | 9 kg | 12 kg | 15 kg |
|---|---|---|---|---|---|
| 0.6 m | > 40 m/s | > 40 m/s | > 40 m/s | > 40 m/s | > 40 m/s |
| 0.8 m | 40 m/s | 38 m/s | 36 m/s | 35 m/s | 33 m/s |
| 1.0 m | 30 m/s | 29 m/s | 27 m/s | 26 m/s | 25 m/s |
| 1.2 m | 24 m/s | 23 m/s | 22 m/s | 21 m/s | 19 m/s |

## Counterweight and elevation servo (calm, EL 0)

Fill needed to balance the dish + feed about the EL axis, capped at the canister's lead-shot capacity; the unbalanced remainder
is what the Stingray-9 (227 kg.cm stall) must hold. The FEA above always uses the capped fill.

| Dish | Mass | Fill needed | Fill used | Unbalanced EL moment | Share of 227 kg.cm |
|---|---|---|---|---|---|
| 0.6 m | 3 kg | 2.6 kg | 2.6 kg | 0 kg.cm | 0 % |
| 0.6 m | 6 kg | 4.6 kg | 4.6 kg | 0 kg.cm | 0 % |
| 0.6 m | 9 kg | 6.6 kg | 6.6 kg | 0 kg.cm | 0 % |
| 0.6 m | 12 kg | 8.7 kg | 7.8 kg | 26 kg.cm | 12 % |
| 0.6 m | 15 kg | 10.7 kg | 7.8 kg | 88 kg.cm | 39 % |
| 0.8 m | 3 kg | 2.9 kg | 2.9 kg | 0 kg.cm | 0 % |
| 0.8 m | 6 kg | 5.1 kg | 5.1 kg | 0 kg.cm | 0 % |
| 0.8 m | 9 kg | 7.2 kg | 7.2 kg | 0 kg.cm | 0 % |
| 0.8 m | 12 kg | 9.4 kg | 7.8 kg | 50 kg.cm | 22 % |
| 0.8 m | 15 kg | 11.6 kg | 7.8 kg | 116 kg.cm | 51 % |
| 1.0 m | 3 kg | 3.2 kg | 3.2 kg | 0 kg.cm | 0 % |
| 1.0 m | 6 kg | 5.5 kg | 5.5 kg | 0 kg.cm | 0 % |
| 1.0 m | 9 kg | 7.8 kg | 7.8 kg | 1 kg.cm | 1 % |
| 1.0 m | 12 kg | 10.2 kg | 7.8 kg | 73 kg.cm | 32 % |
| 1.0 m | 15 kg | 12.5 kg | 7.8 kg | 144 kg.cm | 64 % |
| 1.2 m | 3 kg | 3.4 kg | 3.4 kg | 0 kg.cm | 0 % |
| 1.2 m | 6 kg | 5.9 kg | 5.9 kg | 0 kg.cm | 0 % |
| 1.2 m | 9 kg | 8.5 kg | 7.8 kg | 20 kg.cm | 9 % |
| 1.2 m | 12 kg | 11.0 kg | 7.8 kg | 96 kg.cm | 42 % |
| 1.2 m | 15 kg | 13.5 kg | 7.8 kg | 172 kg.cm | 76 % |

## Where the stress goes (1.0 m, 9 kg, 20 m/s)

| Pose | Wind | columns | cradle (hub/boom/arm) | head (puck/drum/plate) | pedestal | shoulders |
|---|---|---|---|---|---|---|
| EL 0 | head-on (+Y) | 5.29 | 5.89 | 4.08 | 0.98 | 1.52 |
| EL 0 | side (+X) | 1.33 | 5.80 | 2.05 | 0.42 | 3.38 |
| EL 45 | head-on (+Y) | 4.13 | 9.74 | 3.06 | 0.63 | 6.59 |
| EL 45 | side (+X) | 1.21 | 4.99 | 1.92 | 0.39 | 2.98 |
| EL 90 | head-on (+Y) | 1.88 | 3.02 | 1.48 | 0.33 | 3.54 |
| EL 90 | side (+X) | 0.99 | 3.15 | 1.57 | 0.36 | 1.38 |

Full grid: sweep.csv (780 scenarios).

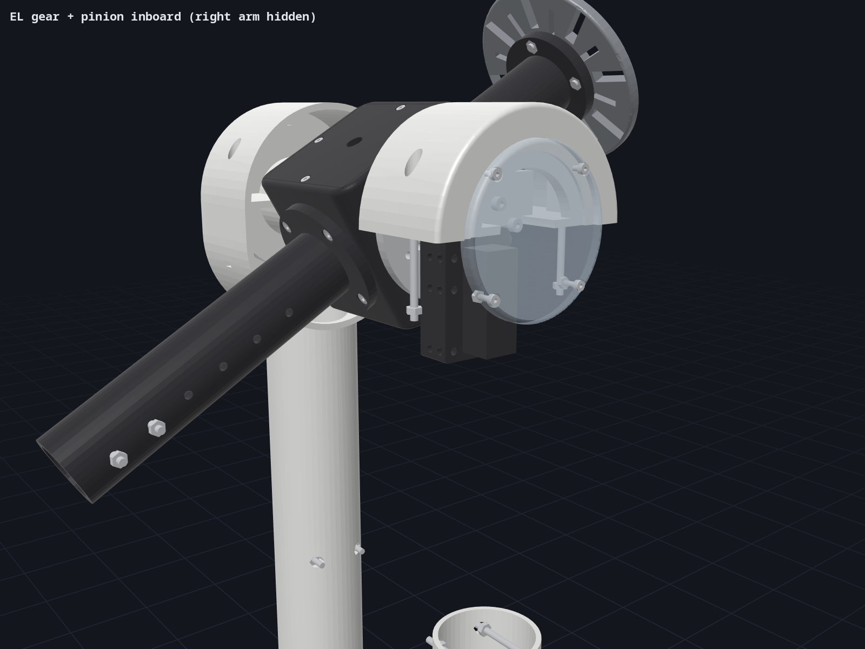
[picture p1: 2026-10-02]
out/renders/el_drive_inboard.png

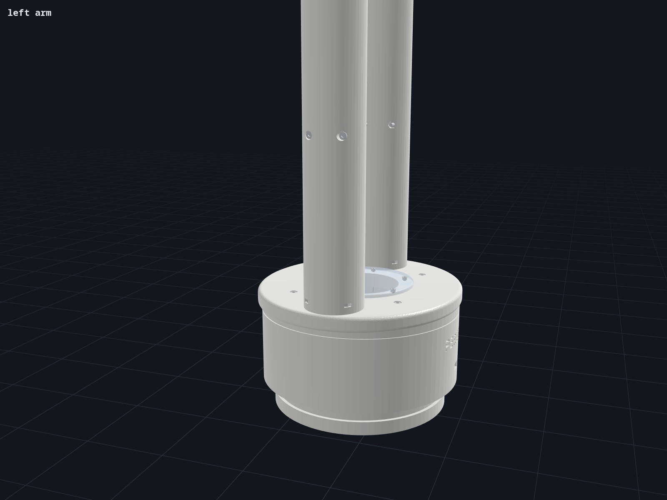
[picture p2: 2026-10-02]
out/renders/arm_left.png

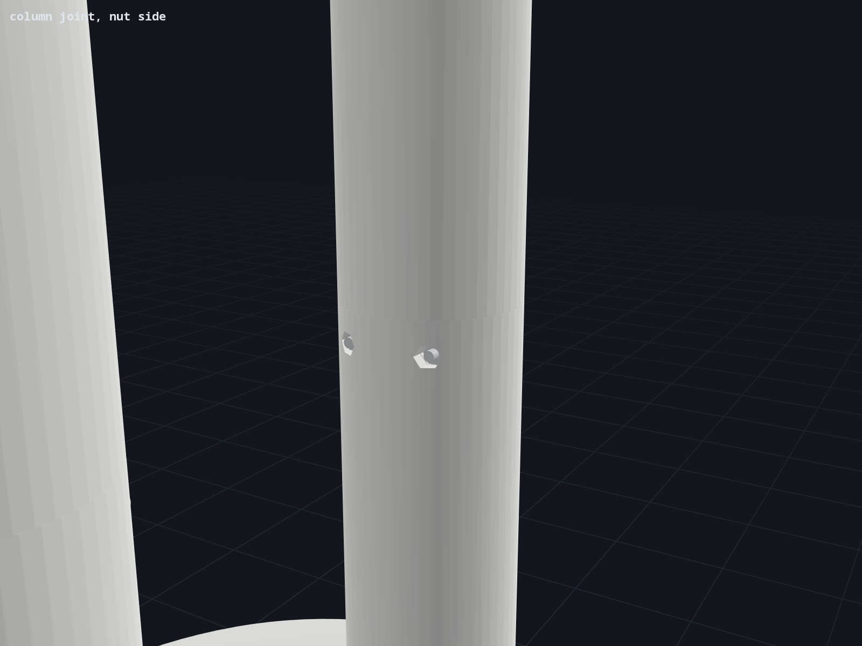
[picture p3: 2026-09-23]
out/renders/column_joint_inner.png

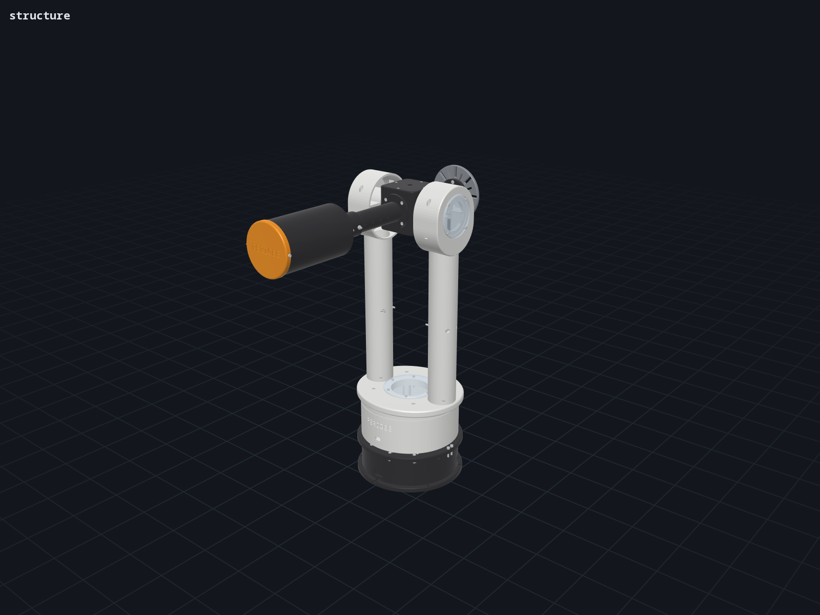
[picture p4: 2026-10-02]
out/renders/no_dish_front.png

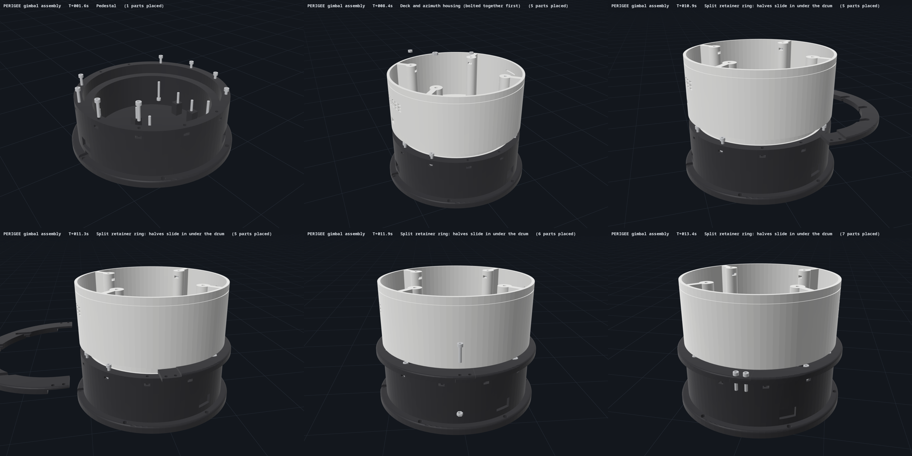
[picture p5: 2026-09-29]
out/renders/contact_sheet.png

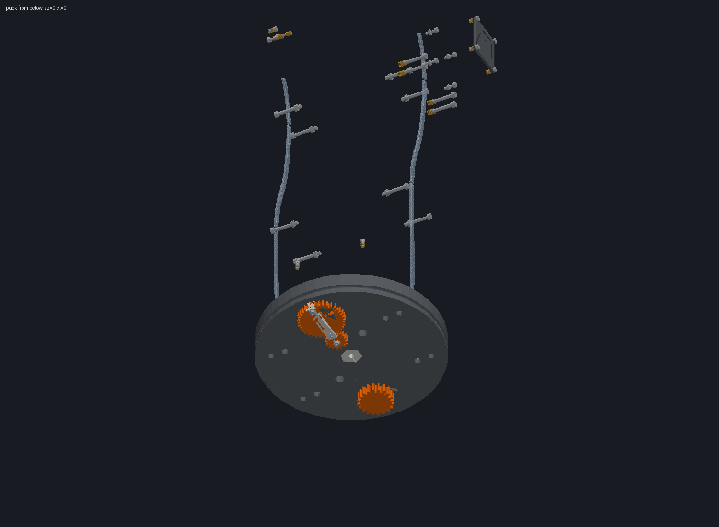
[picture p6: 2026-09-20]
out/renders/head_underside.png

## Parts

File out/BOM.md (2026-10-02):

# Perigee gimbal - bill of materials

Generated by build.py from params.json. Filament mass assumes ~45% effective density (walls + infill); treat as +-30%.

## Printed parts

| Part | Qty | Filament | Solid volume cm3 | Est. mass g | Print bbox mm | Notes |
|---|---|---|---|---|---|---|
| Base_Cup | 1 | black | 1175 | 566 | 236 x 236 x 75 | AZ pedestal. Step at the puck underside (r 84-96) is the greased thrust face; 192 mm bore is the journal. Stingray-4 on four pillars, 4x M4x40 from under the floor. 6x M6 in the foot flange for a mount plate. |
| Az_Retainer_Ring_A | 1 | black | 64 | 31 | 236 x 130 x 8 | Retainer half A (+Y), goes in first: slides in from +Y under the drum, 4 open slots pass the pre-set hook screws (M4x20 into the pedestal nuts); lower tongue of both lap notches with 4 hex pockets underneath for the notch nuts. |
| Az_Retainer_Ring_B | 1 | black | 63 | 30 | 236 x 130 x 8 | Retainer half B (-Y), goes in second: slides in from -Y over A's tongues, 4 open slots pass the hook screws; notch bolts 4x M4x20 down through both tongues. Print with support under the two tongues. |
| Arm_R_1 | 1 | white | 128 | 62 | 180 x 60 x 60 | Lower arm column (R), hollow (3 mm wall), cables inside. Feet 4x M4x25 from under the yoke plate into side-loaded nuts; socket for the upper spigot, 2x M4x50 across. |
| Arm_R_2 | 1 | white | 299 | 144 | 250 x 120 x 60 | Upper arm column + lower half of the shoulder drum (R), 4 mm shell open toward the hub: Stingray-9 channel with a 12 mm back plate (3x M4x20 along the axis into the block's back-face threads, driven through the window; 15 mm pocket for the shaft end), floor and cable opening into the column. |
| El_Bearing_Cap_R | 1 | white | 110 | 53 | 60 x 120 x 60 | Upper half of the shoulder drum, 4 mm shell with a split-plane plate, 2x M4x50 into nuts trapped in the lower half; closes the top of the Stingray-9 channel, carries the upper back-plate screw and the upper half of the two split-plane screw holes. |
| Arm_L_1 | 1 | white | 128 | 62 | 180 x 60 x 60 | Lower arm column (L), hollow (3 mm wall), cables inside. Feet 4x M4x25 from under the yoke plate into side-loaded nuts; socket for the upper spigot, 2x M4x50 across. |
| Arm_L_2 | 1 | white | 280 | 135 | 250 x 120 x 60 | Upper arm column + lower half of the shoulder drum (L), 4 mm shell open toward the hub: pillow block for the left stub bushing, closed by the left axis cover. |
| El_Bearing_Cap_L | 1 | white | 123 | 59 | 60 x 120 x 60 | Upper half of the shoulder drum, 4 mm shell with a split-plane plate, 2x M4x50 into nuts trapped in the lower half; holds the upper bushing half. |
| El_Bushing_L_Lower | 1 | white | 6 | 3 | 40 x 36 x 18 | Half of the split plain bushing (36/30.5 x 40). Grease. |
| El_Bushing_L_Upper | 1 | white | 6 | 3 | 40 x 36 x 18 | Half of the split plain bushing (36/30.5 x 40). Grease. |
| El_Axis_Cap_L | 1 | grey | 31 | 15 | 80 x 80 x 7 | Left axis cover: plain disc closing the stub bushing bore, translucent window; 4x M3x12 into bore-loaded nuts. |
| Status_Window | 1 | clear | 2 | 1 | 39 x 39 x 2 | Translucent disc in the left cap. |
| El_Servo_Cover | 1 | clear | 42 | 20 | 88 x 88 x 7 | Translucent 88 mm lens on the right shoulder drum showing the Stingray-9 and its screws; 4x M3x12 into window-loaded nuts. |
| Head_Puck | 1 | white | 817 | 393 | 191 x 191 x 30 | Rotating deck: 15 mm journal lip + thrust face (grease); bolted to the Stingray-4 standoffs (4x M4x25). Cable loop hole at the back. |
| Az_Drum | 1 | white | 430 | 207 | 216 x 216 x 88 | Rotating azimuth housing (same diameter as the pedestal) = electronics bay. 4 pillars + ribs carry the yoke; M4x30 from below, M4x16 from above, nuts trapped in the pillars. |
| Logo_Light_Pipe | 1 | clear | 3 | 2 | 71 x 8 x 22 | Curved translucent plate behind the drum stencil (glue), LED behind. |
| Yoke_Plate | 1 | white | 568 | 274 | 244 x 220 x 16 | Oval yoke plate / drum lid (244 x 220 mm): pillars 4x M4x16 from above (nuts in the pillars), arm feet 4x M4x25 each from below (nuts in the arm feet), translucent access cover 6x M3x25 (nuts under the plate). |
| Yoke_Access_Cover | 1 | clear | 58 | 28 | 116 x 116 x 7 | Translucent round access cover on the yoke plate (electronics visible); 6x M3x25 + nuts under the plate. |
| Cradle_Hub | 1 | black | 255 | 123 | 90 x 90 x 90 | Hollow rounded hub, open top with a flush bolted lid: every flange bolt (left stub, boom, counterweight arm) ends in a nut inside the cavity; the right wall bolts straight onto the Stingray-9 standoffs. |
| Cradle_Lid | 1 | black | 38 | 18 | 80 x 80 x 6 | Flush hub lid, 4x M3x12 into nuts trapped in the rim. Fit after all flange nuts and the standoff screws are in. |
| El_Stub_L | 1 | black | 59 | 28 | 60 x 60 x 67 | Left EL stub axle, flange 4x M4x20 through the hub wall into nuts inside; turns in the split bushings. |
| Dish_Boom | 1 | black | 101 | 49 | 70 x 115 x 70 | Round boom tube to the dish offset; round root flange 4x M4x20 into nuts inside the hub; round end flange takes either adapter (4x M5 + nuts). |
| Counterweight_Arm | 1 | black | 110 | 53 | 70 x 185 x 70 | Round tube with a row of M4 holes for the canister collar; round root flange 4x M4x20 into nuts inside the hub. |
| Dish_Adapter_Plate | 1 | grey | 72 | 35 | 120 x 120 x 8 | Adapter A: slotted plate; 4x M5x12 into nuts pocketed in the boom flange. |
| Dish_Adapter_PipeStub | 1 | grey | 81 | 39 | 64 x 64 x 108 | Adapter B: 48.3 mm pipe stub. |
| Counterweight_Canister | 1 | black | 183 | 88 | 100 x 100 x 221 | Opaque canister (~1.3 L); collar 2x M4x55 + nuts; cap 2x M3x10 with nuts inside the rim. |
| Counterweight_Cap | 1 | orange | 76 | 37 | 104 x 104 x 10 | Press cap, engraved PERIGEE; 2x M3x10 into nuts pocketed in the plug. |

Estimated total filament: **2555 g**

## Fasteners (every one is modelled in the assembly)

| Item | Qty |
|---|---|
| M3 hex nut | 20 |
| M3 x 10 socket head cap screw | 2 |
| M3 x 12 socket head cap screw | 12 |
| M3 x 25 socket head cap screw | 6 |
| M4 hex nut | 50 |
| M4 x 12 socket head cap screw | 4 |
| M4 x 16 socket head cap screw | 4 |
| M4 x 20 socket head cap screw | 27 |
| M4 x 25 socket head cap screw | 12 |
| M4 x 30 socket head cap screw | 4 |
| M4 x 40 socket head cap screw | 4 |
| M4 x 50 socket head cap screw | 8 |
| M4 x 55 socket head cap screw | 2 |
| M5 hex nut | 4 |
| M5 x 12 socket head cap screw | 4 |

All socket head cap screws are ISO 4762 (DIN 912) and every one ends in an ISO 4032 hex nut in a printed pocket or side-loaded trap; nothing threads into plastic. Tools: 2.5 and 3 mm hex keys, 4 mm for M5, 5.5 / 7 / 8 mm spanners.

## Other hardware

| Item | Qty | Notes |
|---|---|---|
| PTFE or lithium grease | 1 | AZ thrust face + journal, EL bushings, drive-shaft bushing, gear teeth |
| goBILDA Stingray-4 servo gearbox, 3215-0001-0004 (feedback mode) | 1 | AZ direct drive under the deck, 450 deg, 100 kg.cm |
| goBILDA Stingray-9 servo gearbox, 3215-0001-0009 (feedback mode) | 1 | EL direct drive in the right shoulder, 200 deg, 227 kg.cm |
| Cable service loop (450 deg AZ needs no slip ring) | 1 | through the puck hole into the pedestal annulus |
| ST Nucleo-F401RE | 1 | in the electronics bay; both axes open loop, no encoders (the pulse width is the position) |
| HC-05 / HC-06 Bluetooth serial module | 1 | optional PC link instead of USB; not wired yet (needs a spare Nucleo UART) |
| Buck converter 12-24 V -> 5 V | 1 | the HC-05 only, if fitted; the Nucleo runs from 12 V on VIN and the servos from their own rail |
| M6 x 20 bolts | 4 | base floor to your future tripod / mast plate |
| Sand / steel shot / lead shot | 1.3 L | counterweight canister fill (steel shot ~6 kg) |

## Key numbers

- AZ: Stingray-4 direct drive, 450 deg travel (1.25 turns), 15 rpm, 100 kg.cm. EL: Stingray-9 direct drive, 200 deg travel, 6.6 rpm, 227 kg.cm.
- EL axis 599 mm above the base bottom, 510 mm above the deck.
- Dish rim lowest point at EL 0/180: z = 99 mm (base top is 75 mm).
- Counterweight reach at EL 90: 388 mm; yoke plate clearance 18 mm.

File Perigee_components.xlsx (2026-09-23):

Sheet: Printed parts
PERIGEE gimbal, printed components (v8, generated from out/manifest.json; fasteners excluded)
Filament density (g/cm3) | 1.07 | Blue cells are inputs (from params.json). Mass = volume x density x factor x qty.
Effective density factor (walls + infill) | 0.45
# | Part | Sub-assembly | Filament / colour | Qty | Solid volume (cm3) | Est. mass (g) | Print size X (mm) | Print size Y (mm) | Print size Z (mm) | Function / notes
1 | Base_Cup | Pedestal (fixed) | black | 1 | 1174.8 |  | 236 | 236 | 75 | AZ pedestal. Step at the puck underside (r 84-96) is the greased thrust face; 192 mm bore is the journal. Stingray-4 on four pillars, 4x M4x40 from under the floor. 6x M6 in the foot flange for a mount plate.
2 | Az_Retainer_Ring | Pedestal (fixed) | black | 1 | 130.8 |  | 236 | 236 | 8 | Wide flange plate (12x M4x20 + nuts in the pedestal wall) trapping the puck lip: uplift + moment, and the visible AZ seam.
3 | Arm_R_1 | Head (turns in azimuth) | white | 1 | 149.8 |  | 180 | 60 | 60 | Lower arm column (R), hollow, cables inside. Feet 4x M4x25 from under the yoke plate into side-loaded nuts; socket for the upper spigot, 2x M4x50 across.
4 | Arm_R_2 | Head (turns in azimuth) | white | 1 | 519.8 |  | 250 | 150 | 60 | Upper arm column + lower half of the shoulder drum (R): Stingray-9 pocket from the inner face, open cavity behind the translucent lens; block held by 8x M4 from the drum surface.
5 | Arm_L_1 | Head (turns in azimuth) | white | 1 | 148.6 |  | 180 | 60 | 60 | Lower arm column (L), hollow, cables inside. Feet 4x M4x25 from under the yoke plate into side-loaded nuts; socket for the upper spigot, 2x M4x50 across.
6 | Arm_L_2 | Head (turns in azimuth) | white | 1 | 657.9 |  | 250 | 150 | 60 | Upper arm column + lower half of the shoulder drum (L): pillow block for the left stub bushing, on-axis encoder cap.
7 | El_Bearing_Cap_R | Head (turns in azimuth) | white | 1 | 468.6 |  | 60 | 150 | 75 | Upper half of the shoulder drum, 2x M4x25 into nuts trapped in the lower half; closes the top of the gearbox pocket.
8 | El_Bearing_Cap_L | Head (turns in azimuth) | white | 1 | 484.6 |  | 60 | 150 | 75 | Upper half of the shoulder drum, 2x M4x25 into nuts trapped in the lower half; holds the upper bushing half.
9 | El_Bushing_L_Lower | Head (turns in azimuth) | white | 1 | 5.7 |  | 40 | 36 | 18 | Half of the split plain bushing (36/30.5 x 40). Grease.
10 | El_Bushing_L_Upper | Head (turns in azimuth) | white | 1 | 5.7 |  | 40 | 36 | 18 | Half of the split plain bushing (36/30.5 x 40). Grease.
11 | El_Axis_Cap_L | Head (turns in azimuth) | grey | 1 | 33.2 |  | 80 | 80 | 14 | Left axis cap: AS5600 column (2 mm off the stub magnet), translucent window; 4x M3x12 into bore-loaded nuts.
12 | Status_Window | Head (turns in azimuth) | clear | 1 | 2.4 |  | 39.4 | 39.4 | 2 | Translucent disc in the left cap.
13 | El_Servo_Cover | Head (turns in azimuth) | clear | 1 | 49.7 |  | 96 | 96 | 7 | Translucent lens on the right shoulder drum showing the Stingray-9; 4x M3x12 into cavity-loaded nuts.
14 | Head_Puck | Head (turns in azimuth) | white | 1 | 817.2 |  | 191 | 191 | 30 | Rotating deck: 15 mm journal lip + thrust face (grease); bolted to the Stingray-4 standoffs (4x M4x25). Cable loop hole at the back.
15 | Az_Drum | Head (turns in azimuth) | white | 1 | 429.8 |  | 216 | 216 | 88 | Rotating azimuth housing (same diameter as the pedestal) = electronics bay. 4 pillars + ribs carry the yoke; M4x30 from below, M4x16 from above, nuts trapped in the pillars.
16 | Logo_Light_Pipe | Head (turns in azimuth) | clear | 1 | 3.1 |  | 70.7 | 8.1 | 22 | Curved translucent plate behind the drum stencil (glue), LED behind.
17 | Yoke_Plate | Head (turns in azimuth) | white | 1 | 568.2 |  | 244 | 220 | 16 | Oval yoke plate / drum lid (244 x 220 mm): pillars 4x M4x16 from above (nuts in the pillars), arm feet 4x M4x25 each from below (nuts in the arm feet), translucent access cover 6x M3x25 (nuts under the plate).
18 | Yoke_Access_Cover | Head (turns in azimuth) | clear | 1 | 57.6 |  | 116 | 116 | 7 | Translucent round access cover on the yoke plate (electronics visible); 6x M3x25 + nuts under the plate.
19 | Cradle_Hub | Cradle (turns in elevation) | black | 1 | 254.5 |  | 90 | 90 | 90 | Hollow rounded hub, open top with a flush bolted lid: every flange bolt (left stub, boom, counterweight arm) ends in a nut inside the cavity; the right wall bolts straight onto the Stingray-9 standoffs.
20 | Cradle_Lid | Cradle (turns in elevation) | black | 1 | 37.9 |  | 80.4 | 80.4 | 6 | Flush hub lid, 4x M3x12 into nuts trapped in the rim. Fit after all flange nuts and the standoff screws are in.
21 | El_Stub_L | Cradle (turns in elevation) | black | 1 | 58.9 |  | 60 | 60 | 67 | Left EL stub axle, flange 4x M4x20 through the hub wall into nuts inside; turns in the split bushings. Magnet in the end face.
22 | Dish_Boom | Cradle (turns in elevation) | black | 1 | 101.1 |  | 70 | 115 | 70 | Round boom tube to the dish offset; round root flange 4x M4x20 into nuts inside the hub; round end flange takes either adapter (4x M5 + nuts).
23 | Counterweight_Arm | Cradle (turns in elevation) | black | 1 | 109.6 |  | 70 | 185 | 70 | Round tube with a row of M4 holes for the canister collar; round root flange 4x M4x20 into nuts inside the hub.
24 | Dish_Adapter_Plate | Cradle (turns in elevation) | grey | 1 | 71.7 |  | 120 | 120 | 8 | Adapter A: slotted plate; 4x M5x12 into nuts pocketed in the boom flange.
25 | Counterweight_Canister | Cradle (turns in elevation) | black | 1 | 183.3 |  | 100 | 100 | 221 | Opaque canister (~1.3 L); collar 2x M4x55 + nuts; cap 2x M3x10 with nuts inside the rim.
26 | Counterweight_Cap | Cradle (turns in elevation) | orange | 1 | 76.1 |  | 104 | 104 | 10 | Press cap, engraved PERIGEE; 2x M3x10 into nuts pocketed in the plug.
27 | Dish_Adapter_PipeStub | Cradle (turns in elevation) | grey | 1 | 81.4 |  | 64 | 64 | 108 | Adapter B: 48.3 mm pipe stub. (alternative part, printed only if wanted)
 | Total |  |  |  |  |  |  |  |  | The pipe-stub adapter is an alternative to the slotted plate: print one or the other.
Print size is the bounding box in the orientation used for out/stl (all fit a 256 mm bed). Mass assumes ~45 % effective density; treat as +-30 %.

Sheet: Bought components
PERIGEE gimbal, non-printed components (fasteners excluded; those are in out/BOM.md)
# | Component | Sub-assembly | Qty | Part number / spec | Function / notes | Source
1 | goBILDA Stingray-4 servo gearbox (feedback mode) | Pedestal (fixed) / Head | 1 | 3215-0001-0004; 4:1, 450 deg, 100 kg.cm, 15 rpm, 4.8-8.4 V | Direct azimuth drive under the deck; output standoffs bolt to the puck. Its feedback wire gives the AZ position. | gobilda.com (ordered, order #200045873)
2 | goBILDA Stingray-9 servo gearbox (feedback mode) | Head / Cradle | 1 | 3215-0001-0009; 9:1, 200 deg, 227 kg.cm, 6.6 rpm, 4.8-8.4 V | Direct elevation drive inside the right shoulder drum; output standoffs bolt to the cradle hub. | gobilda.com (ordered, order #200045873)
3 | AS5600 magnetic encoder breakout | Head (left axis cap) | 1 | AS5600, 12-bit, I2C | Absolute elevation angle; reads the magnet in the left stub end through the cap column. | generic breakout
4 | Diametric magnet | Cradle (left stub end) | 1 | 6 x 2.5 mm, diametrically magnetised | Target for the AS5600. | generic
5 | Arduino Uno | Head (electronics bay) | 1 | Uno R3 or compatible | Closes the position loop: reads Stingray feedback and AS5600, drives both gearboxes (500-2500 us PWM), unwraps azimuth over 450 deg. | generic
6 | Bluetooth serial module | Head (electronics bay) | 1 | HC-05 or HC-06 | Easycomm II serial link to the PC running Perigee. | generic
7 | Buck converter | Head (electronics bay) | 1 | 12-24 V in, 5 V out, >= 3 A | Powers the Uno, encoder and Bluetooth module. | generic
8 | Servo power supply | Pedestal (fixed) | 1 | 7.4 V, >= 10 A | Feeds both Stingrays; runs up to the head through the cable loop. | generic
9 | Cable service loop | Pedestal / Head | 1 | Flexible multicore, ~1.5 turns of slack | Power and signal across the azimuth joint (450 deg travel, no slip ring). Passes the puck hole into the pedestal annulus. | generic
10 | Grease | Pedestal / Head | 1 | PTFE or lithium | AZ thrust face and journal, EL bushing halves. | generic
11 | Dish (reference only) | Cradle | 1 | up to 1 m mesh, ~9 kg | Modelled as a reference paraboloid; mounts on the boom flange with the slotted adapter or the pipe stub. | user supplied
12 | Counterweight fill | Cradle (canister) | 1 | ~1.3 L of sand, steel shot or lead shot | Balances the dish; steel shot gives ~6 kg. | generic
13 | Mount plate / mast interface | Pedestal (fixed) | 1 | matches the 6x M6 foot-flange pattern on a 236 mm circle | Whatever the pedestal bolts down to. | user supplied
 | Total items

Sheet: By sub-assembly
Printed parts per sub-assembly
Sub-assembly | Printed parts | Total volume (cm3) | Est. mass (g)
Pedestal (fixed)
Head (turns in azimuth)
Cradle (turns in elevation)
Total

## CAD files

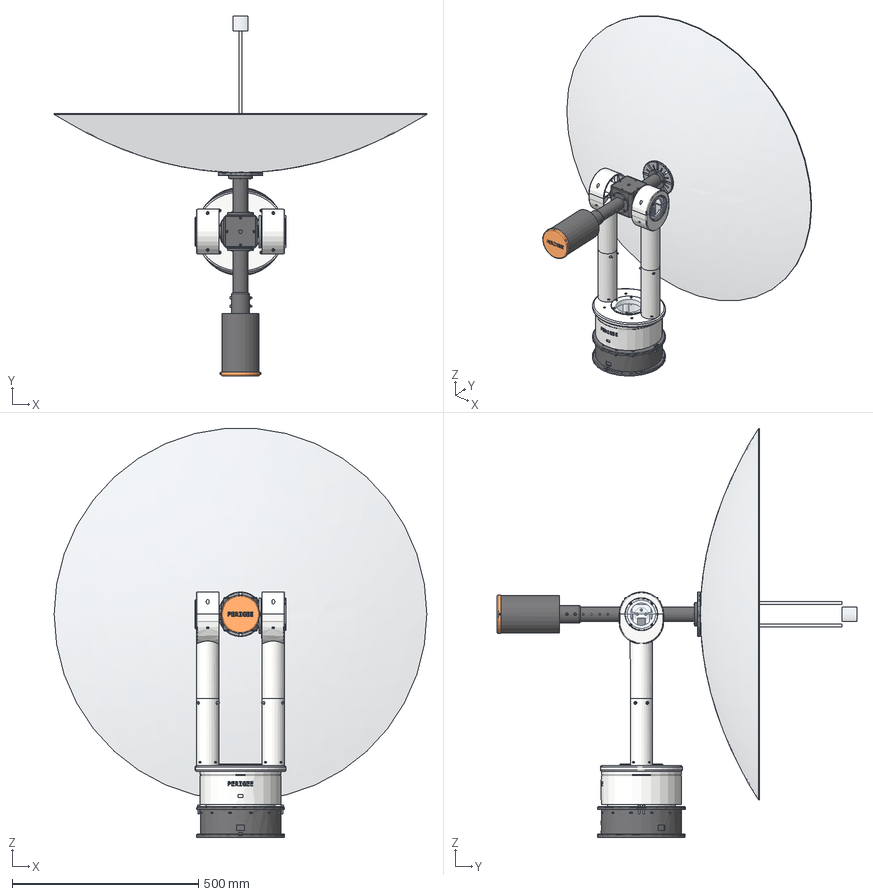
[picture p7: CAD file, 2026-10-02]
out/PerigeeGimbal.FCStd
1000.0 x 965.0 x 1097.3 mm
Base_Cup
Az_Retainer_Ring_A
Az_Retainer_Ring_B
Az_Stingray4
M4 x 40 socket head cap screw x 4
M4 hex nut x 50
M4 x 20 socket head cap screw x 27
Az_Stingray4_Output
Arm_R_1
Arm_R_2
El_Bearing_Cap_R
Arm_L_1
Arm_L_2
El_Bearing_Cap_L
El_Bushing_L_Lower
El_Bushing_L_Upper
El_Axis_Cap_L
Status_Window
El_Servo_Cover
El_Stingray9
Head_Puck
Az_Drum
Logo_Light_Pipe
Yoke_Plate
Yoke_Access_Cover
M3 hex nut x 20
M4 x 50 socket head cap screw x 8
M3 x 12 socket head cap screw x 12
M4 x 25 socket head cap screw x 12
M4 x 30 socket head cap screw x 4
M4 x 16 socket head cap screw x 4
M3 x 25 socket head cap screw x 6
El_Stingray9_Output
Cradle_Hub
Cradle_Lid
El_Stub_L
Dish_Boom
Counterweight_Arm
Dish_Adapter_Plate
Counterweight_Canister
Counterweight_Cap
Dish_Reference_1m
Feed_Reference
M4 x 12 socket head cap screw x 4
M5 x 12 socket head cap screw x 4
M5 hex nut x 4
M4 x 55 socket head cap screw x 2
M3 x 10 socket head cap screw x 2

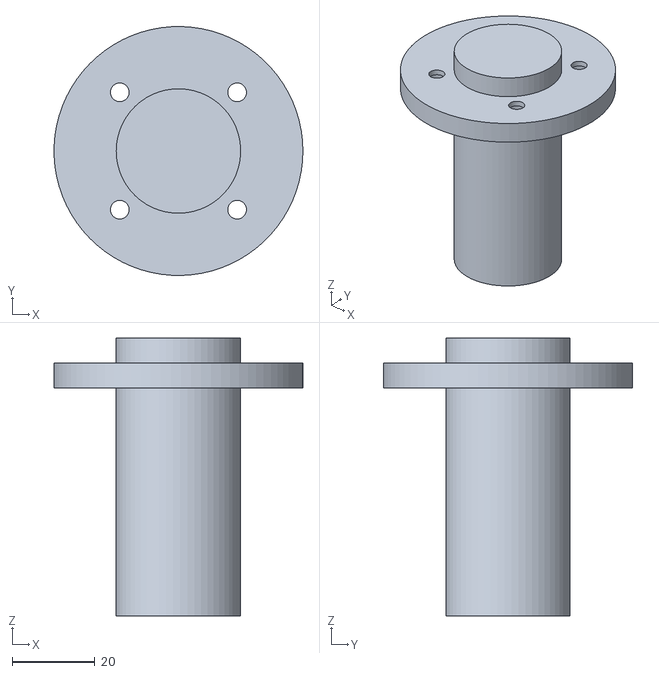
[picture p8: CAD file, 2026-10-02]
out/print/black/El_Stub_L.stl
60.0 x 60.0 x 67.0

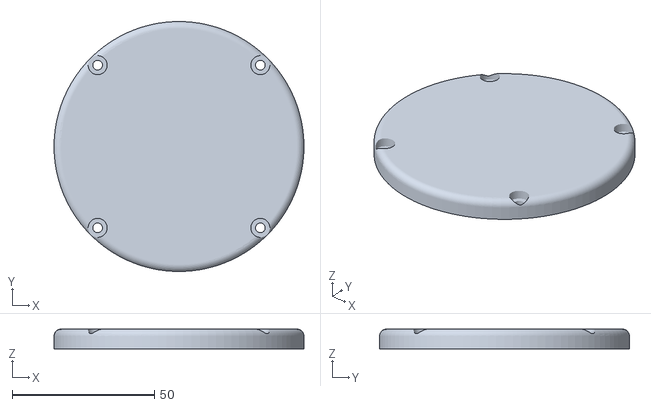
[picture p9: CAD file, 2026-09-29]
out/print/clear/El_Servo_Cover.stl
88.0 x 88.0 x 7.00

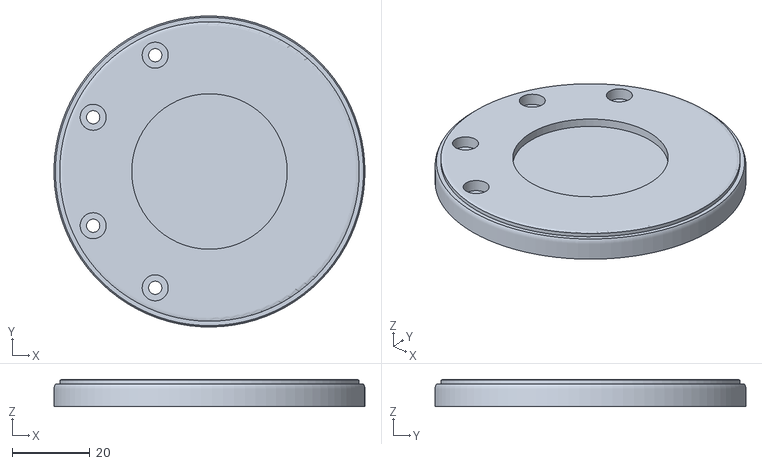
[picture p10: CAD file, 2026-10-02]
out/print/grey/El_Axis_Cap_L.stl
80.0 x 80.0 x 7.00

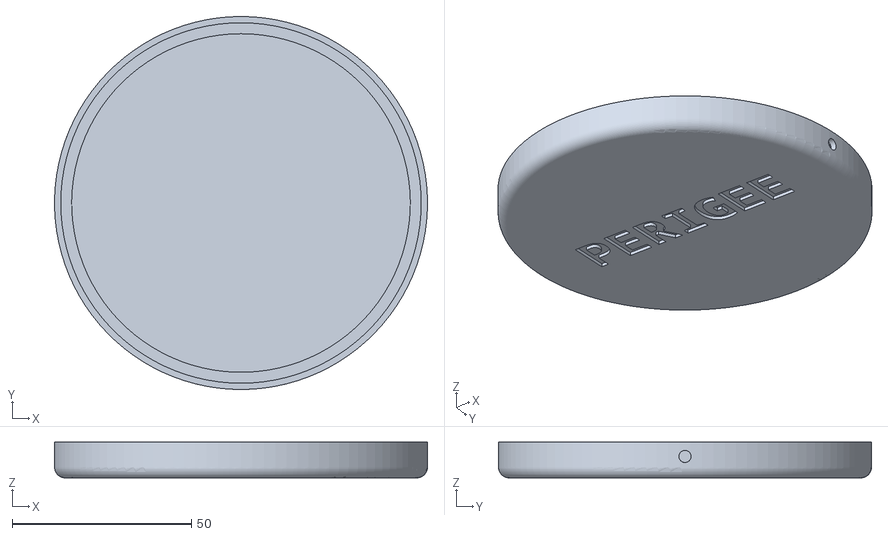
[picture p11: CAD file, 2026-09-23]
out/print/orange/Counterweight_Cap.stl
104.0 x 104.0 x 10.00

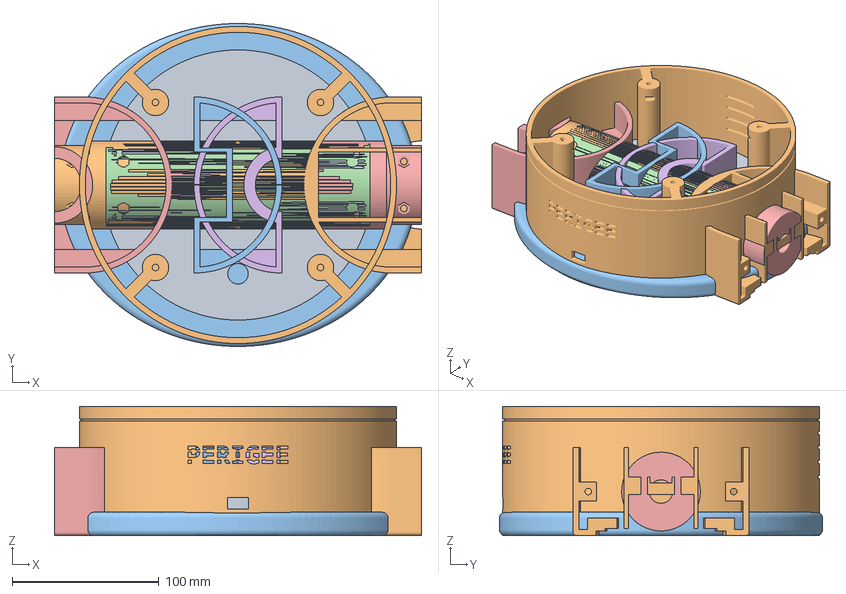
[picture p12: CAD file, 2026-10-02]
out/print/Perigee_white_parts.3mf
250.0 x 220.0 x 88.0 mm

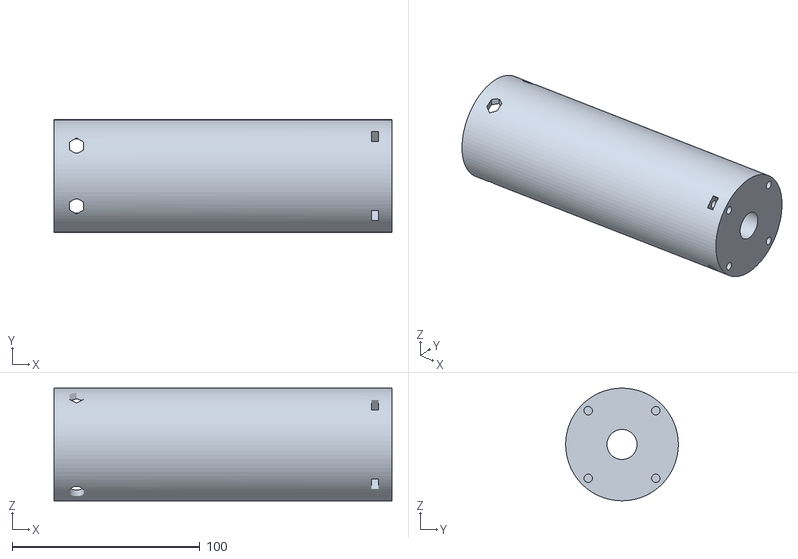
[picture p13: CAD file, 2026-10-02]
out/print/white/Arm_L_1.stl
180.0 x 60.0 x 60.0

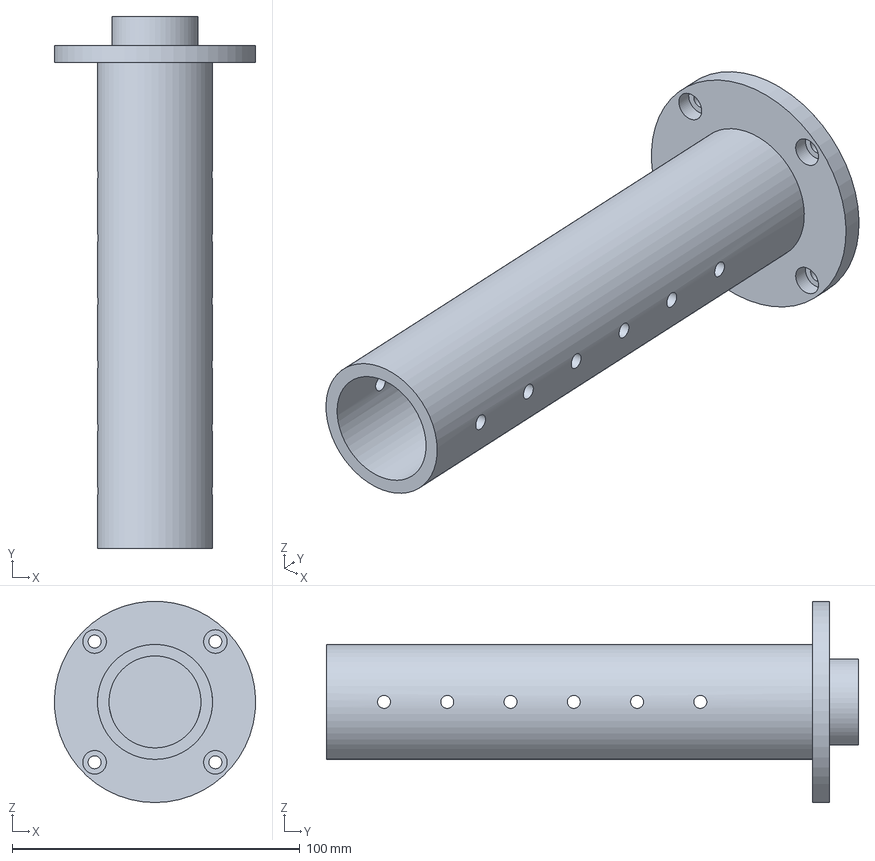
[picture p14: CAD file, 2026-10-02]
out/step/Counterweight_Arm.step
70.0 x 185.0 x 69.9 mm

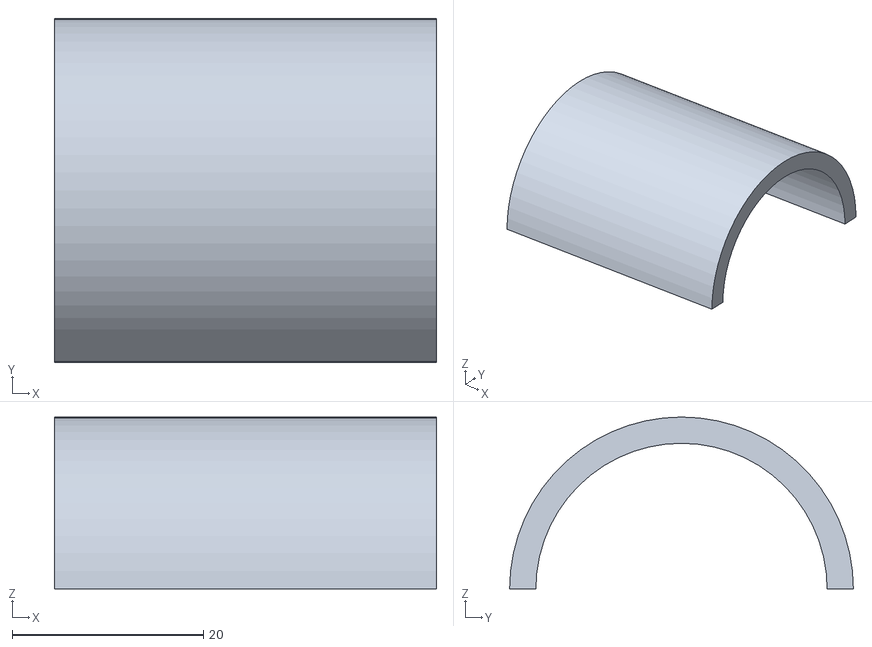
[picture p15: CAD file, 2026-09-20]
out/stl/El_Bushing_R_Upper.stl
40.0 x 36.0 x 18.0

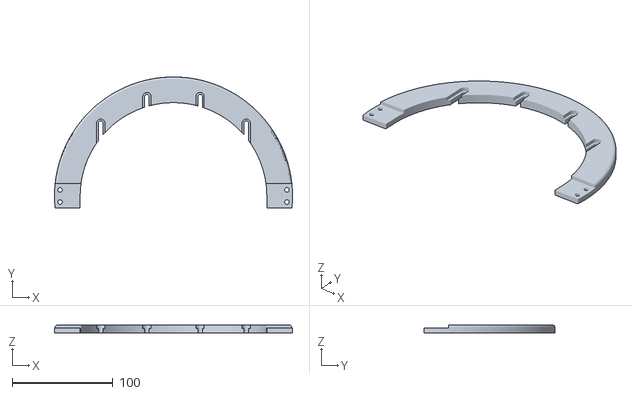
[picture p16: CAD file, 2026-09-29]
out/print/black/Az_Retainer_Ring_A.stl
236.0 x 130.0 x 8.00

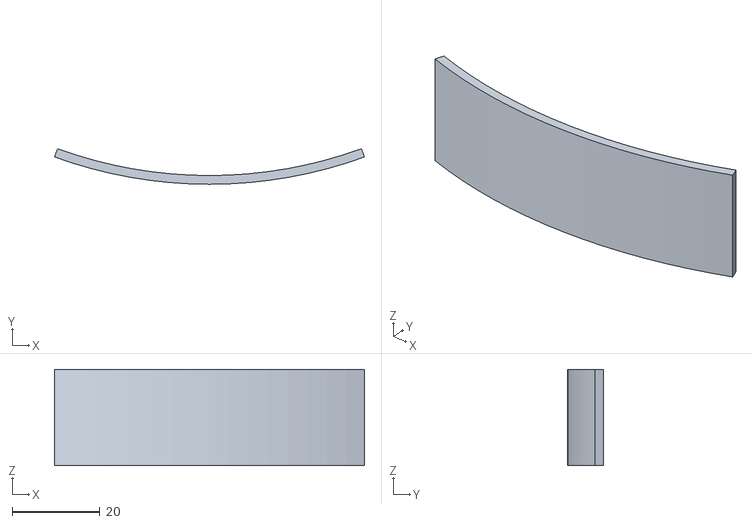
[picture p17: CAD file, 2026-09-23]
out/print/clear/Logo_Light_Pipe.stl
70.7 x 8.12 x 22.0

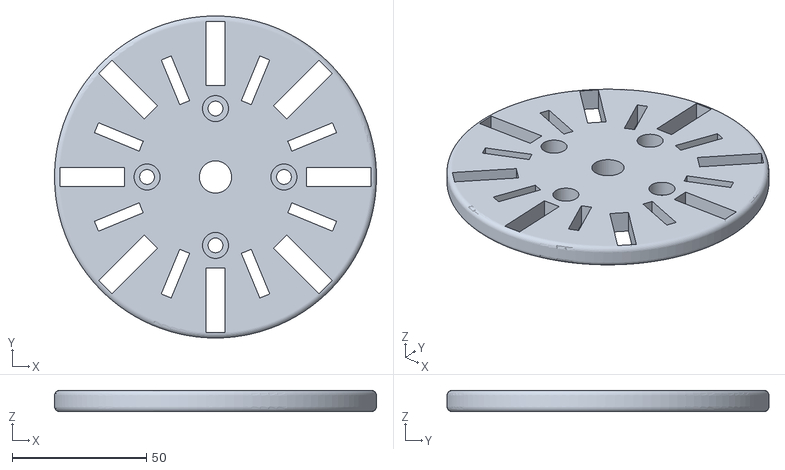
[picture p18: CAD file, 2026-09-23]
out/print/grey/Dish_Adapter_Plate.stl
120.0 x 120.0 x 8.00

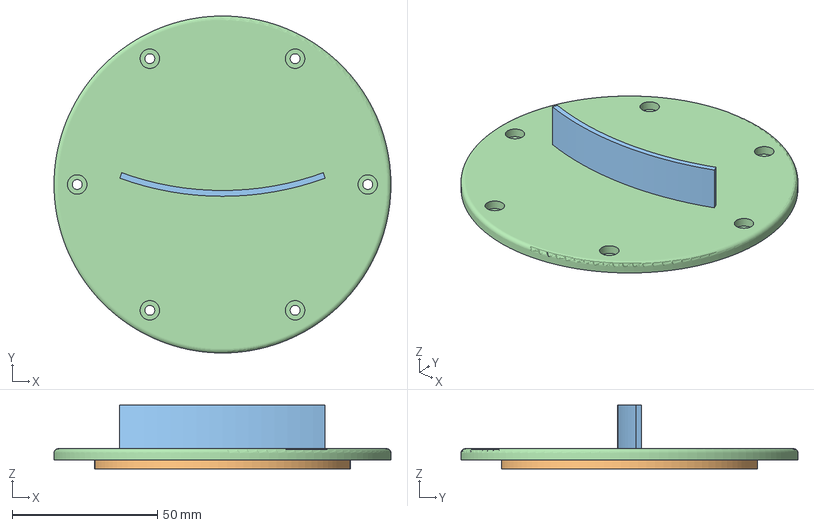
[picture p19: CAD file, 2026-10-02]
out/print/Perigee_clear_parts.3mf
116.0 x 116.0 x 22.0 mm

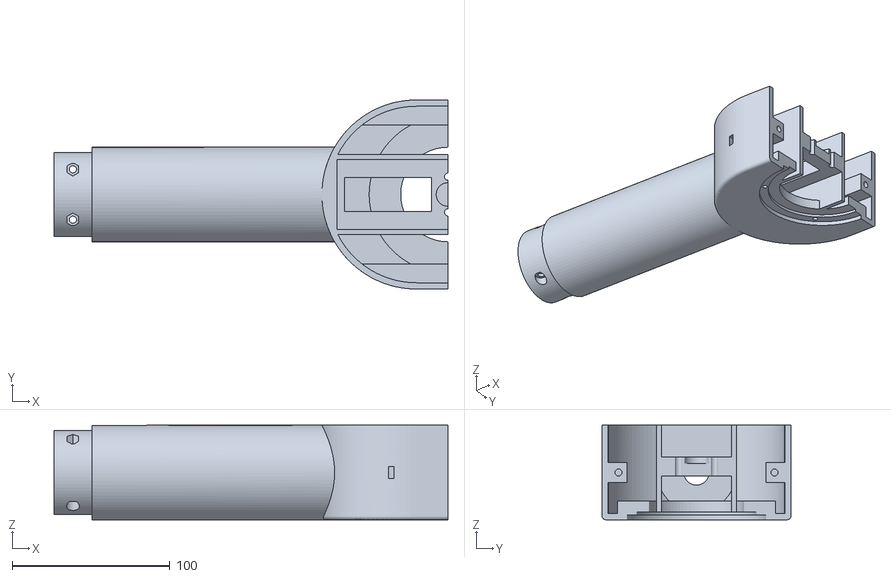
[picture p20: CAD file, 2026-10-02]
out/print/white/Arm_R_2.stl
250.0 x 120.0 x 60.0

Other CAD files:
out/step/El_Servo_Cover.step
out/stl/El_Bushing_R_Lower.stl
out/print/black/Az_Retainer_Ring_B.stl
out/print/clear/Status_Window.stl
out/parts_fcstd/Arm_L_1.FCStd
out/parts_fcstd/Arm_L_2.FCStd
out/parts_fcstd/Arm_R_1.FCStd
out/parts_fcstd/Arm_R_2.FCStd
out/parts_fcstd/Az_Drum.FCStd
out/parts_fcstd/Az_Retainer_Ring_A.FCStd
out/parts_fcstd/Az_Retainer_Ring_B.FCStd
out/parts_fcstd/Base_Cup.FCStd
out/parts_fcstd/Counterweight_Arm.FCStd
out/parts_fcstd/Counterweight_Canister.FCStd
out/parts_fcstd/Counterweight_Cap.FCStd
out/parts_fcstd/Cradle_Hub.FCStd
out/parts_fcstd/Cradle_Lid.FCStd
out/parts_fcstd/Dish_Adapter_PipeStub.FCStd
out/parts_fcstd/Dish_Adapter_Plate.FCStd
out/parts_fcstd/Dish_Boom.FCStd
out/parts_fcstd/El_Axis_Cap_L.FCStd
out/parts_fcstd/El_Bearing_Cap_L.FCStd
out/parts_fcstd/El_Bearing_Cap_R.FCStd
out/parts_fcstd/El_Bushing_L_Lower.FCStd
out/parts_fcstd/El_Bushing_L_Upper.FCStd
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

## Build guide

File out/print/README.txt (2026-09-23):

PERIGEE gimbal print files. One folder per filament colour with every printed part's STL in print orientation, and one 3MF per
colour with all of that colour's parts (open in Bambu Studio, Arrange, split over plates if needed; 256 x 256 bed).
ASA or PETG, 0.2 mm layers, 4-5 walls, 30-40 % gyroid for structural parts. Print one dish adapter only.

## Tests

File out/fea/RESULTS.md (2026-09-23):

# Perigee gimbal FEA, first static case (2026-09-21)

Model: bonded, defeatured structure (tools_fea.py), 215 397 second-order tets / 372 178 nodes, CalculiX 2.23 iterative
Cholesky, converged (14 min on 16 threads). Material: PLA derated for 30 % gyroid, E = 2.1 GPa, yield 30 MPa.
Loads: foot fixed; 88 N dish weight and 130 N horizontal wind at the boom flange; 62 N counterweight at the arm end; gravity.

| Result | Value |
|---|---|
| Peak von Mises | 2.68 MPa at the boom root, just outboard of its hub flange (z 580) |
| 99.9th percentile von Mises | 2.09 MPa |
| Peak by region | columns 2.39, counterweight arm 2.03, drums 1.61, hub+boom 1.38, pedestal 0.86 MPa |
| Safety factor to PLA yield | about 11 |
| Deflection at the EL axis (drums) | 2.65 mm |
| Deflection at the boom flange | 2.9 mm |
| Deflection at the counterweight arm end | 3.6 mm |

Reading: stresses are an order of magnitude below yield everywhere; the structure is stiffness-limited, not strength-limited.
Almost all of the 2.9 mm at the dish is the two columns bending under the 130 N wind (2.65 mm already at the axis), i.e.
about 0.25 deg of tilt at the head, far inside a 1 m dish's beamwidth. The boom itself adds only 0.3 mm over its 158 mm.
Caveats: gearbox blocks and shafts are modelled as PLA (real ones are stiffer), sliding fits are bonded, and the wind is a
single static gust with no dynamic factor; treat deflections as +-30 %.

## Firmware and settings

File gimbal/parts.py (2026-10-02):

"""Part builders for the Perigee gimbal (v8: goBILDA Stingray direct drives, round columns and shoulder drums, bolts + captive nuts).

World coordinates at the nominal pose (az = 0, el = 0, boresight +Y, az axis Z, el axis X).
Drives: a Stingray-4 (450 deg) under the deck turns the head directly, a Stingray-9 (200 deg) in the right shoulder turns the
cradle directly. Both are modelled as measured envelopes of goBILDA's STEP files (vendor/), with their output standoffs,
gears, pinions and the M4 holes that receive screws.
Fastening rule: no threads in plastic. Every bolt ends in a hex nut in a blind hex pocket or a side-loaded nut trap, or in the
gearboxes' own M4 threads.
"""
import math
import FreeCAD as App
import Part
from . import geom as G
from .geom import V, Z, X, Y
from .hardware import Hardware, NUT

COLORS = {
    "black": (0.09, 0.09, 0.10, 0.0), "orange": (1.00, 0.45, 0.05, 0.0), "white": (0.93, 0.93, 0.92, 0.0),
    "grey": (0.42, 0.44, 0.47, 0.0), "clear": (0.80, 0.90, 1.00, 0.55), "ref": (0.55, 0.60, 0.65, 0.75),
    "steel": (0.75, 0.76, 0.78, 0.0), "brass": (0.80, 0.62, 0.25, 0.0),
}
UP, DOWN, PX, NX, PY, NY = (0, 0, 1), (0, 0, -1), (1, 0, 0), (-1, 0, 0), (0, 1, 0), (0, -1, 0)

# goBILDA Stingray servo gearbox, measured from vendor/3215-0001-0004 and -0009 (identical apart from the gear pair).
# Normalised frame: output axis = +Z, load face (standoff ends, shaft end) at z = 0, gearbox below it, servo toward -X.
STINGRAY = {
    "block": (-69.8, 21.8, -21.8, 21.8, -32.6, -12.2),     # aluminium block x0 x1 y0 y1 z0 z1 (91.6 x 43.6 x 20.3)
    "servo": (-65.3, -11.0, -10.3, 10.3, -50.9, -11.0),     # 2000-series servo body standing through the block
    "gear_z": (-10.2, -4.2),                                 # output gear faces
    "hub_r": 16.0, "hub_z": -2.45,                           # hub boss between gear and load face
    "shaft_r": 5.5,                                          # hub-shaft end (8 mm REX) flush with the load face
    "standoff": 8.0, "standoff_af": 7.0,                     # 4x M4 standoffs on a 16 mm square, load interface
    "pinion_x": -48.0, "pinion_z": (-10.4, -4.4),
    "hole_rows_x": (-64.0, -32.0, -16.0, 16.0), "hole_y": 16.0,   # 4.04 mm plain through holes along Z (goBILDA 16 mm grid), NOT tapped
    "side_tap_x": (-64.0, -32.0, -16.0, 16.0), "side_tap_z": (-20.2, -28.2),   # M4 tapped through the block across Y (+-Y faces)
    "back_tap_r": 11.3, "back_tap_ang": (0.0, 90.0, 270.0), "back_tap_depth": 9.3,   # M4 tapped in the back face around the shaft (none at 180, servo side)
    "shaft_back": 3.6, "shaft_back_r": 6.0,                   # hub-shaft end sticks out past the block back face
    "clip_r": 6.6, "clip_t": 0.8,                            # snap ring on the shaft end, proud of the back face
    "clear": 0.5,                                            # pocket clearance around the envelope
}
# gear_r = output gear tip radius; pinion_r is drawn at root radius (centre distance 48) so the two placeholder parts only touch
STINGRAY_KIND = {"4": dict(gear_r=39.2, pinion_r=8.6, label="Stingray-4 (4:1, 450 deg, 100 kg.cm)", sku="3215-0001-0004"),
                 "9": dict(gear_r=44.0, pinion_r=3.8, label="Stingray-9 (9:1, 200 deg, 227 kg.cm)", sku="3215-0001-0009")}


def fillet_edges(shape, radius, pick, label=""):
    """Fillet the edges selected by `pick`; on any failure return the input unchanged and say so in the build log."""
    try:
        edges = [e for e in shape.Edges if pick(e)]
        if not edges:
            if label:
                print("fillet %s: no edges matched" % label)
            return shape
        f = shape.makeFillet(radius, edges)
        if f.isValid() and len(f.Solids) == 1:
            return f
        if label:
            print("fillet %s: result invalid, skipped" % label)
    except Exception as ex:
        if label:
            print("fillet %s: failed (%s), skipped" % (label, str(ex).strip()[:60]))
    return shape


def side_name(sgn):
    return "R" if sgn > 0 else "L"


class Layout:
    def __init__(self, P):
        self.P = P
        self.z_floor = P["base_floor"]
        self.z_puck0 = P["puck_z0"]; self.z_deck = self.z_puck0 + P["puck_h"]
        self.R_lip = P["puck_od"] / 2; self.R_body = P["puck_body_od"] / 2; self.z_lip1 = self.z_puck0 + P["puck_lip_h"]
        self.R_base = P["base_od"] / 2; self.R_pedestal = P["base_body_od"] / 2; self.R_bore = P["base_wall_inner_r"]; self.R_thrust = P["thrust_ring_r"]
        self.z_base_top = P["base_h"]; self.z_ret1 = self.z_base_top + P["retainer_h"]
        self.R_drum = P["drum_od"] / 2; self.z_drum1 = self.z_deck + P["drum_h"]
        self.z_plate1 = self.z_drum1 + P["yoke_plate_h"]
        self.z_el = self.z_deck + P["el_axis_height"]
        self.x_arm_in = P["arm_inner_x"]; self.x_arm_out = self.x_arm_in + P["arm_thick"]; self.x_arm_mid = (self.x_arm_in + self.x_arm_out) / 2
        self.arm_r = P["arm_thick"] / 2                          # arms are round columns
        self.r_ret_bolt = (self.R_bore + self.R_pedestal) / 2   # retainer bolts run down the middle of the pedestal wall
        self.r_mount_bolt = (self.R_pedestal + self.R_base) / 2  # M6 mount holes in the foot flange
        self.r_axle = P["el_axle_d"] / 2; self.r_bush = P["el_bushing_od"] / 2
        self.R_sh = P["shoulder_r"]; self.x_sh_out = self.x_arm_in + P["shoulder_thick"]
        self.sh_drop = P["shoulder_drop"]; self.sh_wall = P["shoulder_wall"]; self.arm_wall = P["arm_wall"]   # stadium drop below the axis, shell and column walls
        self.arm_splits = [self.z_plate1, self.z_el - (P["segment_max"] - 30), self.z_el]   # upper piece + 24 mm spigot stays under segment_max
        self.hub = P["hub_size"]; self.hub_wall = P["hub_wall"]
        self.x_stub_end = self.x_sh_out - 12                    # left stub axle end
        self.y_boom_end = P["dish_offset"]; self.y_cw_end = -(self.hub / 2 + P["cw_arm_len"])
        self.pillar_r = self.R_body - 12.5                     # pillars stand on the puck body, tied to the drum wall by ribs
        self.r_adapter_bolt = 25.5   # boom end flange bolts, on the axes so the M5 nut pockets sit outside the 40 mm square tube
        S = STINGRAY
        # EL Stingray-9: load face on the hub's right wall, gearbox in the right shoulder, servo below the axis
        self.x_el_load = self.hub / 2
        self.z_el_servo = self.z_el + (S["servo"][0] + S["servo"][1]) / 2       # servo centre height (cover axis)
        self.x_el_block = (self.x_el_load - S["block"][5], self.x_el_load - S["block"][4])     # 57.2 .. 77.6
        self.x_el_servo1 = self.x_el_load - S["servo"][4]                        # outer end of the servo, 95.9
        # AZ Stingray-4: load face on the puck underside, servo toward +Y
        self.z_az_block0 = self.z_puck0 + S["block"][4]                          # block underside, pillars stand under it
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

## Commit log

2026-09-20 PERIGEE gimbal: parametric FreeCAD generator, exports, viewer and film
    Fully 3D-printed az/el pedestal mount for a 1 m mesh dish (CMG-ISS proportions):
    printed plain bearings only, bolts with captive nuts only, AS5600 encoders on both
    axes, slip-ring powered Arduino head. Includes the FreeCAD generator (build.py,
    gimbal/), params.json, exported FCStd/STEP/STL/DXF, BOM, moderngl renderer with
    the assembly film pipeline, three.js viewer and GUI macros.
    [01_Base.dxf, 02_Head_Puck.dxf, 03_Arms_Right.dxf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]
2026-09-23 Stingray-4/-9 direct drives and round columns (v8.1), print files, FEA sweep tooling and report
    - tools_fea_poses.py: bonded structure rebuilt at EL 0 / 45 / 90
    - tools_fea_sweep.py: gmsh meshes, 9 CalculiX unit-load steps per pose, linear superposition over
    dish size x mass x wind speed x direction x pose -> out/fea/sweep/SWEEP.md, sweep.csv
    - vendor STEP files and FEA meshes/results are ignored (size); reports are tracked
    [01_Base.dxf, 02_Head_Puck.dxf, 03_Arms_Right.dxf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]
2026-09-29 v10: split azimuth retainer ring so the drum goes on last
    Ring is two halves with lap notches: 8 of the 12 pedestal traps keep nuts (the hooks), the
    four at 15/165/195/345 deg join the halves instead. Rebuilt FCStd, per-part files, BOM and
    manifest to match.
    [Arm_L_1.FCStd, Arm_L_1.step, Arm_L_1.stl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]
2026-10-02 v11: Stingray-9 screwed into its back-face threads (grid holes are plain, not tapped), 12 mm back plate with shaft-end pocket; AS5600 and magnet dropped (both axes open loop on a Nucleo-F401RE); rege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
    [Arm_L_1.FCStd, Arm_L_1.step, Arm_L_1.stl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]
